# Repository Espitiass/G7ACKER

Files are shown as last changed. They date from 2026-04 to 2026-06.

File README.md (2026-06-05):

# 🤖 G7ACKER - Robot Móvil Autónomo con Visión Artificial

Sistema de robot móvil con conducción autónoma basado en visión artificial, diseñado para navegación en entornos estructurados mediante seguimiento de carril, detección de obstáculos y dirección tipo Ackermann.

---

# 📖 Descripción del Proyecto

El proyecto consiste en el desarrollo de un robot móvil autónomo que integra procesamiento visual, sensores de proximidad y control embebido distribuido para lograr un desplazamiento inteligente sin intervención humana.

El sistema está orientado a simular escenarios reales de movilidad autónoma, como vehículos terrestres a pequeña escala que operan sobre carriles definidos.

El enfoque del proyecto combina:

- Visión artificial para percepción del entorno
- Detección de estaciones mediante sensor infrarrojo
- Control distribuido (Raspberry Pi + ESP32)
- Sistema de dirección tipo Ackermann

---

# 🎥 Demo del Sistema

## Funcionamiento del robot

> *(Agregar imágenes, GIF o enlace de video del funcionamiento)*

---

# 🔄 Flujo del Sistema

```text
[Cámara IMX219]
        ↓
[Procesamiento en Raspberry Pi (OpenCV)]
        ↓
[Decisiones de navegación]
        ↓
[ESP32]
        ↓
[Driver TB6612FNG]
        ↓
[Motores JGY-370 + Servo MG90]
```

---

# 🛠️ Hardware del Sistema

## 🧠 Unidad de procesamiento

- Raspberry Pi 5
- ESP32

---

## 📡 Sensores

- Cámara IMX219 (visión artificial)
- Sensor ultrasónico HC-SR04 (detección frontal de obstáculos)
- 1 Sensor infrarrojo TCRT5000 (detección lateral de estaciones de carga y descarga)

---

## ⚙️ Actuadores

- 2 Motores DC JGY-370
- Servo motor MG90 (engranajes metálicos)

---

## 🚗 Sistema de dirección

- Configuración tipo Ackermann

---

## ⚡ Etapa de potencia

- Driver TB6612FNG Dual Motor

---

## 🔋 Alimentación

- Batería LiPo 7.4V – 5A
- Regulador XL4016 (salida a 5V, alta corriente)
- Regulador LM2596 (salida a 3.3V)

---

# 💻 Software y Tecnologías

| Tecnología | Uso |
|---|---|
| Python | Lógica principal y visión artificial |
| OpenCV | Procesamiento de imagen |
| ESP32 (C/C++) | Control embebido |
| Serial USB | Comunicación Raspberry Pi ↔ ESP32 |

---

# 📂 Estructura del Repositorio

```text
G7ACKER/
├── .vscode/                          # Configuración de Visual Studio Code
│   └── settings.json
│
├── docs/                             # Documentación del proyecto
│   ├── acta_constitucion/
│   ├── bitacoras/
│   ├── imagenes/
│   ├── matriz_control_de_documentos/
│   ├── poster/
│   ├── presentacion_final/
│   └── README.md
│
├── hardware/                         # Diseño electrónico y PCB
│   ├── esquematico/
│   ├── pcb/
│   └── README.md
│
├── mechanical/                       # Diseño mecánico y estructural
│   ├── Diseños_de_prueba/
│   ├── Diseños_finales/
│   └── README.md
│
├── src/                              # Código fuente
│   ├── Autonomía_básica/
│   ├── Control_de_motores/
│   ├── Pruebas/
│   └── README.md
│
├── .gitignore
├── LICENSE
├── README.md
├── Scriptsactivate
└── test.jpg
```

---

# 📊 Estado del Proyecto

| Módulo | Estado |
|---|---|
| Diseño electrónico | ✅ Completado |
| PCB | ✅ Fabricada y operativa |
| Sistema mecánico | ✅ Completado |
| Visión artificial | ✅ Integrada y funcional |
| Control autónomo | 🧪 Pruebas finales |

---

# 👥 Autores

| Integrante | Área |
|---|---|
| Sofía Salomé Espitia Jiménez | Área de diseño |
| Vanesa Galeano Franco | Área de programación |
| Julián Andrés García Correa | Área eléctrica y electrónica |
| Jose Lisander Hurtado Castañeda | Área mecánica |

---

# 📄 Licencia

Este proyecto se distribuye bajo la licencia MIT License.

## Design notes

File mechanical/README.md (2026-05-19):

# 🔧 Mechanical

Esta carpeta contiene todo el desarrollo mecánico del robot móvil **G7ACKER**, incluyendo diseños CAD, prototipos, soportes estructurales y versiones finales utilizadas durante la construcción del sistema robótico.

El objetivo principal de este módulo es diseñar y fabricar la estructura física del robot, garantizando:

- Resistencia mecánica
- Estabilidad estructural
- Integración electrónica
- Soporte de sensores
- Sistema de dirección
- Sistema de tracción
- Modularidad del diseño

Todos los componentes fueron desarrollados considerando la integración entre:

- Raspberry Pi 5
- ESP32
- Sensores
- Sistema de locomoción
- Cámaras
- Actuadores

---

# 📂 Estructura de la carpeta

La carpeta se encuentra dividida en dos grandes secciones:

| Carpeta | Descripción |
|---|---|
| `Diseños_de_prueba` | Modelos preliminares y prototipos utilizados durante el desarrollo |
| `Diseños_finales` | Versiones finales implementadas en el robot |

---

# 🧪 Diseños_de_prueba

Esta sección contiene las primeras iteraciones y prototipos mecánicos desarrollados durante la etapa de diseño del robot.

Aquí se realizaron pruebas relacionadas con:

- Dimensiones del chasis
- Sistemas de dirección
- Ubicación de sensores
- Integración de cámara
- Soportes estructurales
- Distribución de componentes

Los modelos incluidos permitieron validar conceptos antes de fabricar las versiones finales.

## 📁 Contenido

### `bases`
Diseños iniciales del chasis y estructura principal del robot.

### `Camara`
Primeros soportes y adaptaciones para el montaje de la cámara del sistema de visión.

### `direccion_v1`
Primera versión del sistema de dirección mecánica.

### `direccion_v2`
Segunda iteración del mecanismo de dirección con mejoras estructurales y de movilidad.

### `traccion_v1`
Primer prototipo del sistema de tracción y montaje de motores.

---

# ✅ Diseños_finales

Esta sección contiene las piezas y modelos mecánicos definitivos utilizados en la construcción final del robot G7ACKER.

Los diseños finales fueron optimizados para:

- Mejor estabilidad
- Integración electrónica
- Facilidad de ensamblaje
- Reducción de vibraciones
- Organización del cableado
- Soporte robusto de sensores

## 📁 Contenido

### `Bases`
Estructura principal final del robot, utilizada para soportar todos los módulos mecánicos y electrónicos.

### `direccion_v3`
Versión final del sistema de dirección implementado en el robot.

Incluye mejoras en:

- Precisión de giro
- Resistencia mecánica
- Integración con servomotor
- Estabilidad de movimiento

### `Soporte_camara`
Soporte definitivo para la cámara principal utilizada por el sistema de visión artificial.

### `soporte_infrarrojo`
Estructura diseñada para fijar y posicionar el sensor infrarrojo del robot.

### `soporte_lipo_v1`
Soporte mecánico para la batería LiPo utilizada como fuente de alimentación del sistema.

### `soporte_ultrasonico`
Montaje diseñado para el sensor ultrasónico encargado de la detección de obstáculos.

### `Tracción`
Sistema final de montaje de motores, ruedas y transmisión del robot móvil.

---

# ⚙️ Diseño mecánico del robot

El diseño mecánico del robot fue desarrollado utilizando herramientas CAD y técnicas de fabricación digital.

El sistema fue diseñado considerando:

- Distribución de peso
- Centro de gravedad
- Espacio para electrónica
- Accesibilidad de mantenimiento
- Modularidad
- Expansión futura

La estructura permite integrar de manera eficiente todos los módulos electrónicos y sensores del sistema autónomo.

---

# 🛠️ Fabricación

Las piezas fueron diseñadas principalmente para fabricación mediante impresión 3D, utilizando materiales termoplásticos compatibles con tecnologías FDM.

Esto permitió:

- Fabricación rápida de prototipos
- Iteración constante de diseños
- Reducción de costos
- Personalización de componentes

---

# 🚗 Función dentro del proyecto

El módulo mecánico constituye la base física del robot móvil G7ACKER.

Su función principal es proporcionar:

- Soporte estructural
- Integración de sensores
- Sistema de locomoción
- Protección de componentes electrónicos
- Plataforma de navegación autónoma

La integración entre diseño mecánico, electrónica y software permitió construir un sistema robótico funcional, modular y escalable.

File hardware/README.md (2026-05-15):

# Diseño Electrónico

Esta carpeta contiene el desarrollo del sistema electrónico del robot G7ACKER, incluyendo el diseño del esquemático y la PCB utilizada para la integración del sistema.

---

## Estructura

```text
hardware/
│── esquematico/
│── pcb/
```

---

## Contenido

### Esquemático

Incluye la representación del sistema electrónico antes de su implementación física:

* Imagen del esquemático por medio de ilustración en el sofware DRAW.IO (formato PNG) para visualización rápida
* Archivo original del esquemático (formato `.sch`) con todas las conexiones y componentes definidos
* Imagen del esquematico original en FUSION

Este diseño permite validar la correcta interconexión de los módulos antes de avanzar al diseño de la PCB.

---

### PCB

Contiene el diseño final de la placa electrónica:

* Archivo de la PCB con ruteo completo (formato `.f3z`, Fusion 360)
* Modelo 3D de la PCB (formato `.brd`)
* Imagen del ruto de la pcb en FUSION

Este diseño corresponde a la versión enviada a fabricación, incluyendo:

* Rutas eléctricas
* Distribución de componentes
* Integración del sistema completo

---

## Propósito

* Documentar el diseño electrónico del sistema
* Facilitar la fabricación de la PCB
* Permitir la revisión y modificación del circuito
* Servir como base para futuras iteraciones

---

## Notas

* Mantener consistencia entre esquemático y PCB
* Verificar nombres de componentes y conexiones
* Evitar modificaciones directas sobre versiones finales sin control

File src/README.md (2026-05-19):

# 📁 Carpeta de Código Fuente 

En esta carpeta se encuentra el **código fuente del robot móvil autónomo G7ACKER**, desarrollado para implementar las funcionalidades principales de **control, percepción, comunicación y pruebas del sistema**.

Aquí se almacenan los diferentes scripts utilizados durante el desarrollo del proyecto, incluyendo módulos de control de hardware, visión artificial, comunicación serial y pruebas individuales de componentes.

El objetivo de esta carpeta es **centralizar todo el software del sistema**, permitiendo organizar, modificar y escalar el desarrollo del robot de manera estructurada.

---

# 🧩 Estructura del proyecto

La organización del código se divide en diferentes módulos según la funcionalidad desarrollada dentro del robot.

---

## 🤖 Autonomía_básica/

Esta carpeta contiene los algoritmos relacionados con la **navegación autónoma básica del robot**, incluyendo seguimiento de carriles, detección de obstáculos y toma de decisiones sobre la pista.

La carpeta se divide en dos versiones principales:

### 📂 V1/

Contiene la primera versión funcional del sistema de autonomía básica del robot.

En esta etapa se desarrollaron e integraron:

- Seguimiento de líneas o carriles.
- Detección de obstáculos mediante sensor ultrasónico.
- Control básico de desplazamiento autónomo.

Esta versión representa la primera implementación estable de navegación autónoma sobre pista.

---

### 📂 V2/

Corresponde a la versión más reciente y estructurada del sistema de autonomía básica.

Esta versión divide las funciones principales del robot en diferentes módulos:

- `main.py`  
  Archivo principal encargado de iniciar y coordinar la ejecución del sistema.

- `motor_control.py`  
  Gestiona el control de movimiento del robot, la activación de motores y la comunicación con la ESP32.

- `qr_logic.py`  
  Procesa la información obtenida mediante lectura de códigos QR y toma decisiones de navegación dentro de la pista.

Esta estructura modular permite separar la lógica de navegación, percepción y control, facilitando la organización y escalabilidad del proyecto.

---

## ⚙️ Control_de_motores/

Esta carpeta contiene el código desarrollado para el control de los motores y actuadores del robot desde la ESP32.

Aquí se encuentra la versión final del sistema de control:

- `control_1.2.cpp`

Este código es el encargado de:

- Recibir las instrucciones enviadas desde la Raspberry Pi 5.
- Interpretar los comandos de movimiento.
- Controlar los motores mediante señales enviadas al driver.
- Ejecutar acciones como avance, retroceso, giros y detención del robot.

Además, dentro de esta carpeta se encuentran versiones previas y pruebas realizadas durante el desarrollo del sistema de control.

---

## 🧪 Pruebas/

Esta carpeta contiene todas las pruebas realizadas de manera independiente sobre sensores, actuadores y sistemas de comunicación del robot.

El objetivo de estas pruebas es:

- Validar el funcionamiento individual de cada componente.
- Detectar errores antes de integrar los módulos al sistema principal.
- Facilitar la depuración del hardware y software.
- Comprobar estabilidad y comunicación entre dispositivos.

Dentro de esta carpeta se incluyen pruebas relacionadas con:

### 📷 Cámara
Pruebas de captura de imagen, procesamiento y funcionamiento de la cámara.

### 🔌 Comunicación serial
Pruebas de comunicación entre Raspberry Pi y ESP32.

### 📡 Sensores
Pruebas individuales de sensores ultrasónicos, sensores IR y finales de carrera.

### ⚙️ Motores
Pruebas de velocidad, RPM, encoders y control de motores.

### 🔄 Servo motores
Pruebas de funcionamiento y posicionamiento del servomotor.

### 🏁 Integración final
Pruebas completas del comportamiento del robot sobre la pista.

---

# ⚙️ Organización del código

El proyecto sigue un enfoque de desarrollo **modular**, donde cada archivo cumple una función específica dentro del sistema general del robot.

Esta metodología permite:

- Facilitar la comprensión del sistema.
- Mejorar la depuración del código.
- Integrar nuevas funcionalidades sin afectar otros módulos.
- Mantener un desarrollo organizado y escalable.
- Favorecer el trabajo colaborativo dentro del equipo.

Además, se manejan múltiples versiones y pruebas progresivas para validar el funcionamiento del robot antes de integrar cada componente al sistema principal.

---

# 🚀 Desarrollo continuo

El proyecto se encuentra en constante evolución, por lo que esta carpeta seguirá creciendo con nuevos módulos y mejoras relacionadas con:

- Navegación autónoma
- Visión artificial
- Integración de sensores
- Comunicación entre sistemas
- Optimización de control
- Automatización de decisiones
- Mejora del rendimiento general del robot

Por esta razón, el contenido de esta carpeta puede actualizarse continuamente a medida que avance el desarrollo del robot móvil autónomo G7ACKER.

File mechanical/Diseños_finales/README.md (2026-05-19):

# 📁 Diseños_finales

La carpeta `Diseños_finales` contiene las versiones finales y optimizadas de los componentes mecánicos utilizados en el robot móvil **G7ACKER**.

Estos diseños corresponden a las iteraciones definitivas desarrolladas después de las etapas de prueba y validación mecánica realizadas durante el prototipado inicial del robot.

En esta sección se consolidan los modelos utilizados para:

- Chasis estructural
- Sistema de dirección Ackerman
- Sistema de tracción
- Soportes electrónicos
- Integración de sensores
- Sistema de cámara
- Distribución mecánica final

Todos los modelos fueron desarrollados para fabricación mediante impresión 3D y ensamblaje modular.

---

# 📂 Estructura de archivos

Dentro de cada subcarpeta se incluyen principalmente los siguientes tipos de archivos:

| Extensión | Descripción |
|---|---|
| `.f3d` | Archivo editable de Autodesk Fusion 360 |
| `.stl` | Modelo 3D listo para impresión |
| `.pdf` | Documento técnico o plano de referencia |

Los archivos `.f3d` permiten modificar los diseños mecánicos, mientras que los `.stl` corresponden a versiones preparadas para fabricación mediante impresión 3D.

---

# 📁 Bases

La carpeta `Bases` contiene los diseños estructurales finales del chasis principal del robot.

Estos modelos fueron desarrollados para proporcionar:

- Rigidez estructural
- Distribución de carga
- Espacio para electrónica
- Integración de sensores
- Soporte para sistemas mecánicos

## 📄 Componentes principales

| Archivo | Descripción |
|---|---|
| `Base piso de carga 3 carga.f3d` | Diseño estructural principal del piso de carga |
| `Base piso de carga 3 carga.stl` | Modelo STL del piso de carga |
| `Base Piso_1 mot_ack.f3d` | Base estructural para integración del sistema Ackerman |
| `Base Piso_2 electronica.f3d` | Base destinada al montaje electrónico |
| `base_piso_1_mat_ack.f3d` | Variante estructural del sistema Ackerman |
| `Base_Piso_2_electronica.pdf` | Plano técnico de integración electrónica |

---

# 📁 direccion_v3

La carpeta `direccion_v3` contiene la tercera versión del sistema de dirección mecánica del robot.

Esta versión incorpora mejoras estructurales y funcionales orientadas a:

- Mayor precisión de giro
- Mejor estabilidad mecánica
- Reducción de holguras
- Integración optimizada del servomotor
- Mayor resistencia estructural

El diseño continúa basado en un sistema tipo Ackerman para mejorar el control de trayectoria del robot.

## 📄 Componentes principales

| Componente | Función |
|---|---|
| `Acople rueda delantera.pdf` | Plano técnico del acople de rueda delantera |
| `Barra direccion version 3.pdf` | Documento técnico de la barra de dirección |
| `barra_direccion_v3.f3d` | Diseño editable de la barra de dirección |
| `barra_direccion_v3.stl` | Modelo imprimible de la barra de dirección |
| `barra_soportes_giratorios_v3.f3d` | Soporte estructural giratorio |
| `barra_soportes_giratorios_v3.stl` | Modelo STL del soporte giratorio |
| `base_brazo_servo.f3d` | Base de integración del brazo del servomotor |
| `base_brazo_servo.stl` | Modelo STL del brazo del servo |
| `bujes_rigidez.f3d` | Elementos de refuerzo estructural |
| `bujes_rigidez.stl` | Modelo imprimible de los bujes |
| `Soporte giratorio ackerman.pdf` | Plano del soporte Ackerman |
| `Soporte servo RH.pdf` | Plano técnico del soporte derecho del servo |
| `soporte_giratorio_ackerman.f3d` | Diseño del soporte Ackerman |
| `soporte_giratorio_ackerman.stl` | Modelo STL del soporte Ackerman |
| `soporte_servo_der.f3d` | Soporte derecho del servomotor |
| `soporte_servo_der.stl` | Modelo imprimible del soporte derecho |
| `soporte_servo_izq.f3d` | Soporte izquierdo del servomotor |
| `soporte_servo_izq.stl` | Modelo imprimible del soporte izquierdo |

Todos los componentes se encuentran disponibles en formatos editables y preparados para impresión 3D.

---

# 📁 Soporte camara

La carpeta `Soporte camara` contiene los diseños finales del sistema de soporte de cámara del robot.

Estos modelos fueron desarrollados para garantizar:

- Estabilidad mecánica
- Correcto ángulo de visión
- Integración con Raspberry Pi
- Protección estructural de la cámara
- Modularidad de ensamblaje

## 📄 Componentes principales

| Componente | Función |
|---|---|
| `base camara.f3d` | Base principal del sistema de cámara |
| `base camara.stl` | Modelo STL de la base |
| `Ensamble camara 2.f3d` | Ensamble mecánico del sistema de cámara |
| `Ensamble camara 2.stl` | Modelo STL del ensamble |
| `Pilar camara V3.f3d` | Pilar estructural de soporte |
| `Pilar camara V3.stl` | Modelo imprimible del pilar |
| `Soporte superior camara.f3d` | Soporte superior del sistema |
| `Soporte superior camara.stl` | Modelo STL del soporte superior |

---

# 📁 soporte_infrarrojo

La carpeta `soporte_infrarrojo` contiene el soporte mecánico diseñado para la integración de sensores infrarrojos.

Estos diseños permiten:

- Montaje seguro del sensor
- Correcta orientación de lectura
- Protección mecánica
- Integración con el chasis

## 📄 Archivos principales

| Archivo | Descripción |
|---|---|
| `soporte_infrarrojo.f3d` | Diseño editable del soporte infrarrojo |
| `soporte_infrarrojo.stl` | Modelo STL listo para impresión |

---

# 📁 soporte_lipo_v1

La carpeta `soporte_lipo_v1` contiene el sistema de soporte diseñado para la batería LiPo utilizada en el robot.

Este soporte fue desarrollado para:

- Fijación segura de batería
- Distribución de peso
- Protección mecánica
- Fácil mantenimiento

## 📄 Archivos principales

| Archivo | Descripción |
|---|---|
| `soporte_bateria_v1.f3d` | Diseño editable del soporte de batería |
| `soporte_bateria_v1.stl` | Modelo STL para impresión 3D |

---

# 📁 soporte_ultrasonico

La carpeta `soporte_ultrasonico` contiene los soportes mecánicos destinados a sensores ultrasónicos del robot.

Estos componentes permiten:

- Integración estructural del sensor
- Correcta orientación de medición
- Protección física
- Fácil montaje sobre el chasis

## 📄 Archivos principales

| Archivo | Descripción |
|---|---|
| `soporte_ultrasonico.f3d` | Diseño editable del soporte ultrasónico |
| `soporte_ultrasonico.stl` | Modelo imprimible del soporte |

---

# 📁 Tracción

La carpeta `Tracción` contiene los diseños finales del sistema de transmisión y montaje de motores del robot.

Estos modelos fueron desarrollados para optimizar:

- Integración de motores
- Acople de ruedas
- Distribución de fuerza
- Estabilidad mecánica
- Soporte estructural del sistema de tracción

## 📄 Componentes principales

| Componente | Función |
|---|---|
| `Acople de la llanta al GearBox.pdf` | Plano técnico del sistema de acople |
| `acople_llanta_motor.f3d` | Diseño editable del acople rueda-motor |
| `acople_llanta_motor.stl` | Modelo STL del acople |
| `Soporte de motor derecho.pdf` | Plano técnico del soporte derecho |
| `Soporte de motor izquierdo.pdf` | Plano técnico del soporte izquierdo |
| `soporte_motor_derecho.f3d` | Soporte estructural derecho |
| `soporte_motor_derecho.stl` | Modelo imprimible del soporte derecho |
| `soporte_motor_izquierdo.f3d` | Soporte estructural izquierdo |
| `soporte_motor_izquierdo.stl` | Modelo imprimible del soporte izquierdo |

---

# 🛠️ Fabricación de componentes

Todos los modelos STL incluidos en esta carpeta fueron diseñados para fabricación mediante impresión 3D utilizando tecnología FDM.

Esto permitió:

- Fabricación rápida de componentes
- Ajustes iterativos
- Validación física de piezas
- Reducción de costos
- Desarrollo modular del robot

---

# ⚙️ Flujo de desarrollo mecánico

El proceso de diseño utilizado para el desarrollo de los componentes finales siguió una metodología iterativa basada en:

1. Diseño CAD en Fusion 360.
2. Simulación y validación estructural.
3. Exportación de archivos STL.
4. Impresión 3D de prototipos.
5. Ensamble mecánico.
6. Integración electrónica.
7. Pruebas funcionales.
8. Optimización final.

---

# 🚀 Importancia dentro del proyecto

Los diseños finales representan la consolidación del sistema mecánico desarrollado para el robot móvil autónomo G7ACKER.

Gracias a esta etapa fue posible:

- Obtener un sistema mecánico estable
- Mejorar la precisión de dirección
- Optimizar la integración electrónica
- Reducir vibraciones estructurales
- Mejorar la distribución de peso
- Facilitar el ensamblaje modular
- Garantizar compatibilidad con sensores y actuadores

Esta carpeta contiene los modelos definitivos utilizados en la construcción física del robot.

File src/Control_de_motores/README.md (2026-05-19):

# ⚙️ Control de Motores

Esta carpeta contiene el desarrollo del sistema de **control de movimiento del robot móvil G7ACKER**, implementado sobre un microcontrolador ESP32.

El objetivo principal de este módulo es recibir las instrucciones enviadas desde la Raspberry Pi y convertirlas en acciones físicas sobre el robot, controlando:

- Motores de tracción
- Dirección del sistema
- Velocidad de desplazamiento
- Lectura de encoders
- Control PWM
- Servomotor de dirección

Este sistema constituye la capa de ejecución del robot, encargada de transformar las decisiones del sistema autónomo en movimiento real.

---

# 📂 Contenido de la carpeta

Dentro de esta carpeta se encuentran distintas versiones y pruebas relacionadas con el control de motores del robot.

La versión principal y final utilizada en el proyecto corresponde a:

- `control_1.2.cpp`

Además, se incluyen archivos de prueba y calibración utilizados durante el desarrollo.

---

# 📄 control_1.2.cpp

El archivo `control_1.2.cpp` corresponde a la versión final del sistema de control implementado en el ESP32.

Este código se encarga de:

- Recibir comandos desde la Raspberry Pi mediante comunicación serial.
- Controlar los motores DC del robot.
- Gestionar el movimiento diferencial.
- Accionar el servomotor de dirección.
- Leer encoders para medición de velocidad.
- Ejecutar el control de tracción del robot.

---

# 🔌 Comunicación con Raspberry Pi

El ESP32 recibe comandos enviados desde la Raspberry Pi mediante comunicación serial USB.

Los comandos implementados son:

| Comando | Acción |
|---|---|
| `a` | Avanzar |
| `i` | Girar izquierda |
| `d` | Girar derecha |
| `x` | Detener |

Cada instrucción es interpretada por el ESP32 para ejecutar el movimiento correspondiente sobre el sistema de tracción.

Esta arquitectura permite separar:

- Raspberry Pi → procesamiento y toma de decisiones.
- ESP32 → control físico de actuadores.

---

# 🚗 Sistema de movimiento

El robot utiliza un sistema de tracción diferencial compuesto por:

- Dos motores DC con caja reductora.
- Driver de potencia.
- Control PWM independiente para cada motor.

El código controla de manera individual ambos motores para generar:

- Movimiento frontal
- Correcciones de trayectoria
- Giros
- Frenado

---

# ⚡ Control PWM

La velocidad de los motores se regula mediante señales PWM generadas por el ESP32.

El sistema utiliza:

- Canal PWM independiente para cada motor.
- Frecuencia configurada a 5 kHz.
- Resolución de 8 bits.

Esto permite controlar la velocidad del robot de manera eficiente y suave.

---

# 📏 Calibración de motores

Debido a diferencias mecánicas entre motores, se implementaron ecuaciones de calibración independientes para cada lado del sistema de tracción.

Estas ecuaciones permiten compensar diferencias de velocidad y mantener un desplazamiento más estable y recto.

El sistema utiliza constantes de ajuste para:

- Motor izquierdo
- Motor derecho

De esta manera se mejora la precisión del movimiento autónomo del robot.

---

# 🔄 Control diferencial

El movimiento del robot se implementa mediante lógica diferencial.

Dependiendo del comando recibido:

- Ambos motores avanzan.
- Un motor se detiene.
- Se generan correcciones de dirección.

Esto permite realizar giros y ajustes de trayectoria sin necesidad de mecanismos complejos de dirección.

---

# 🎯 Control del servomotor

El sistema incorpora un servomotor encargado de modificar la dirección mecánica del robot.

El servo se posiciona según el movimiento solicitado:

| Dirección | Ángulo aproximado |
|---|---|
| Centro | 90° |
| Derecha | 150° |
| Izquierda | 30° |

El código evita movimientos innecesarios del servo utilizando una variable de control que detecta cambios de dirección.

Esto reduce vibraciones y mejora la estabilidad mecánica.

---

# 📡 Lectura de encoders

El sistema utiliza encoders para medir la velocidad de rotación de los motores.

Las señales de encoder son capturadas mediante interrupciones del ESP32 para obtener:

- Pulsos por revolución (PPR)
- RPM
- Velocidad lineal aproximada

Esto permite monitorear el comportamiento real de los motores durante el desplazamiento.

---

# ⚙️ Arquitectura del sistema

El código fue desarrollado utilizando una estructura modular basada en funciones independientes para:

- Movimiento de motores
- Frenado
- Control PWM
- Lectura de encoders
- Movimiento del servo
- Aplicación de trayectorias

Esta organización facilita:

- Mantenimiento del código
- Escalabilidad
- Pruebas individuales
- Depuración del sistema

---

# 🧪 Desarrollo y pruebas

Durante el desarrollo se realizaron múltiples pruebas relacionadas con:

- Control de velocidad
- Estabilidad del movimiento
- Respuesta del servo
- Comunicación serial
- Medición de RPM
- Ajuste de PWM
- Corrección de trayectoria

Las distintas versiones del código reflejan el proceso iterativo de mejora del sistema de locomoción.

---

# 🚀 Función dentro del robot

Este módulo representa la capa de ejecución física del robot móvil G7ACKER.

Mientras la Raspberry Pi procesa información del entorno y toma decisiones autónomas, el ESP32 ejecuta dichas acciones controlando directamente los actuadores del sistema.

La integración entre ambos dispositivos permite implementar un sistema robótico distribuido, modular y escalable.

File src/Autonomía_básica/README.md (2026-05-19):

# 🤖 Autonomía Básica

Esta carpeta contiene el desarrollo del sistema de **autonomía básica del robot móvil G7ACKER**, encargado del seguimiento de líneas, detección de obstáculos, lectura de códigos QR/AprilTags y toma de decisiones dentro de la pista.

Aquí se encuentran las diferentes versiones del sistema autónomo implementadas durante el desarrollo del proyecto, permitiendo observar la evolución desde las primeras pruebas funcionales hasta la arquitectura final de navegación.

El objetivo principal de esta sección es integrar los módulos de:

- Visión artificial
- Seguimiento de carriles
- Detección de obstáculos
- Comunicación con el ESP32
- Navegación autónoma
- Toma de decisiones basada en señales visuales

---

# 📂 Estructura de la carpeta

La carpeta se divide en dos versiones principales del sistema:

- `V1/` → Primera versión funcional del sistema autónomo.
- `V2/` → Versión final e integrada de autonomía básica.

---

# 🔹 V1 — Primera versión funcional

La carpeta `V1` contiene la primera implementación estable del sistema de autonomía básica del robot.

Esta versión se enfocó principalmente en:

- Seguimiento de líneas mediante visión artificial.
- Detección de obstáculos usando sensor ultrasónico.
- Comunicación serial con el ESP32.
- Visualización del procesamiento en tiempo real mediante Flask.

---

## ⚙️ Funcionalidades implementadas en V1

### 👁️ Detección de carriles

El sistema utiliza una cámara conectada a la Raspberry Pi para capturar imágenes en tiempo real y detectar las líneas de navegación presentes en la pista.

Para ello se implementaron técnicas de procesamiento de imagen utilizando OpenCV:

- Conversión a espacio de color HSV.
- Aplicación de máscaras por color.
- Filtrado morfológico.
- Detección de contornos.
- Cálculo dinámico del centro del carril.

El algoritmo identifica las líneas izquierda y derecha de la pista y calcula el error respecto al centro de la imagen para corregir la trayectoria del robot.

---

### 📡 Detección de obstáculos

Se integró un sensor ultrasónico conectado a la Raspberry Pi mediante GPIO para detectar obstáculos frente al robot.

El sistema realiza múltiples lecturas consecutivas para reducir ruido y falsas detecciones.

Cuando un objeto es detectado a una distancia menor al umbral establecido:

- El robot detiene inmediatamente su movimiento.
- Se bloquea el envío de comandos de avance.
- Se muestra el estado del sensor en el stream de video.

---

### 🔌 Comunicación serial con ESP32

La Raspberry Pi envía comandos de movimiento al ESP32 mediante comunicación serial USB.

Los comandos implementados permiten:

- Avanzar
- Girar a la izquierda
- Girar a la derecha
- Detener el robot

Esta arquitectura divide el sistema en:

- Raspberry Pi → procesamiento y toma de decisiones.
- ESP32 → ejecución de movimiento y control de motores.

---

### 📺 Streaming en tiempo real

La versión V1 implementa un servidor Flask para visualizar el procesamiento de imagen en tiempo real desde cualquier navegador conectado a la red local.

El stream incluye:

- Detección de líneas
- Contornos encontrados
- Centro del carril
- Estado del ultrasonido
- Dirección actual
- Comando enviado

Esto permitió facilitar el proceso de depuración y ajuste del sistema autónomo.

---

# 🔹 V2 — Versión final de autonomía básica

La carpeta `V2` contiene la arquitectura final del sistema autónomo del robot.

Esta versión integra:

- Seguimiento de líneas
- Detección de obstáculos
- Lectura de QR / AprilTags
- Máquina de estados
- Navegación por estaciones
- Comunicación entre procesos
- Control inteligente de recorrido

La arquitectura fue separada en múltiples módulos para mejorar:

- Organización del código
- Escalabilidad
- Mantenimiento
- Depuración

---

# 📄 main.py

El archivo `main.py` actúa como el núcleo principal del sistema autónomo.

Su función es:

- Inicializar el sistema.
- Crear procesos independientes.
- Gestionar la comunicación entre módulos.
- Ejecutar el sistema de navegación.

Para ello se implementa `multiprocessing`, permitiendo ejecutar distintos procesos simultáneamente sin bloquear el procesamiento de cámara.

---

## 🔄 Comunicación entre procesos

El sistema utiliza colas (`Queue`) para compartir información entre módulos:

- `qr_queue` → IDs detectados.
- `action_queue` → acciones de movimiento.
- `line_status_queue` → estado de detección de líneas.
- `status_queue` → información general del robot.

Esta arquitectura modular facilita el intercambio de información entre los distintos componentes del sistema autónomo.

---

# 📄 motor_control.py

El archivo `motor_control.py` es el encargado del procesamiento principal relacionado con:

- Visión artificial
- Seguimiento de línea
- Lectura de QR
- Detección de obstáculos
- Comunicación serial
- Streaming del sistema

Este módulo constituye el núcleo de percepción del robot.

---

## 👁️ Seguimiento de línea

El sistema detecta líneas de color mediante OpenCV utilizando máscaras HSV y análisis de contornos.

A partir de la posición del carril detectado se calcula el error respecto al centro de la imagen para decidir:

- Avanzar
- Girar a la izquierda
- Girar a la derecha
- Detenerse

---

## 📷 Lectura de QR y AprilTags

La versión V2 incorpora un sistema de lectura de QR/AprilTags utilizado para identificar estaciones y tomar decisiones dentro de la pista.

El sistema:

- Detecta marcos visuales.
- Se aproxima automáticamente.
- Captura la región de interés.
- Decodifica el identificador.
- Envía la información al módulo lógico.

Esto permite que el robot navegue de forma autónoma según el recorrido establecido.

---

## 📡 Sensor ultrasónico

El módulo también integra el sensor ultrasónico para detener el robot ante obstáculos cercanos.

La prioridad del sensor es superior al seguimiento de línea, por lo que cualquier detección bloquea inmediatamente el movimiento del robot.

---

## 📺 Visualización y depuración

El sistema genera un stream de video en tiempo real mostrando:

- Estado actual
- Carriles detectados
- Detección de QR
- Comandos enviados
- Distancia detectada
- Variables internas del sistema

Esto facilita el monitoreo del comportamiento autónomo durante las pruebas.

---

# 📄 qr_logic.py

El archivo `qr_logic.py` contiene la lógica de navegación y toma de decisiones del robot.

Este módulo implementa una máquina de estados encargada de interpretar los IDs detectados y decidir el comportamiento del robot dentro de la pista.

---

# 🧠 Máquina de estados

La lógica del sistema se organiza mediante estados secuenciales que representan cada etapa del recorrido.

Algunos estados implementados son:

- Espera de carga
- Espera de objetivo
- Espera de giro
- Espera de descarga
- Fin de recorrido

Cada transición depende de:

- IDs detectados
- Sensores
- Estado del robot
- Posición dentro de la pista

---

# 🗺️ Mapa de tags

El sistema utiliza un diccionario (`MAPA_TAGS`) donde cada ID representa una acción o estación específica.

Por ejemplo:

- Estaciones de carga
- Estaciones de descarga
- Intersecciones
- Direcciones de giro
- Finales de recorrido

Esto permite modificar el comportamiento del robot simplemente cambiando la configuración lógica de los tags.

---

# 📡 Integración de sensores

Además de la visión artificial, este módulo integra:

- Sensor infrarrojo
- Final de carrera
- Estado de líneas detectadas

La combinación de sensores permite aumentar la confiabilidad del sistema de navegación autónoma.

---

# ⚙️ Arquitectura modular

La versión V2 fue desarrollada siguiendo una arquitectura modular distribuida, donde cada archivo cumple una función específica dentro del sistema.

Esto permite:

- Escalar funcionalidades.
- Modificar módulos sin afectar el resto del sistema.
- Facilitar pruebas individuales.
- Mejorar la mantenibilidad del proyecto.

---

# 🚀 Evolución del sistema

La transición de V1 a V2 representa la evolución del robot desde un sistema básico de seguimiento de líneas hasta una plataforma de navegación autónoma capaz de:

- Interpretar señales visuales.
- Tomar decisiones.
- Navegar entre estaciones.
- Gestionar recorridos.
- Integrar múltiples sensores.
- Coordinar distintos procesos simultáneamente.

Esta arquitectura constituye la base del sistema autónomo implementado en el robot móvil G7ACKER.

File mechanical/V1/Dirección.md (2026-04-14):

# Dirección

El sistema de **dirección del robot** fue diseñado utilizando **Autodesk Fusion 360**, con el objetivo de implementar un mecanismo de giro preciso que permita orientar las ruedas delanteras del robot durante su desplazamiento.

Para este proyecto se estableció un sistema de **dirección tipo Ackermann**, ampliamente utilizado en vehículos terrestres debido a su capacidad de reducir el deslizamiento lateral de las ruedas durante los giros. Este tipo de mecanismo permite que cada rueda del eje delantero describa un radio de giro diferente, mejorando la eficiencia del movimiento y la estabilidad del robot.

El sistema de dirección es accionado mediante un **servo motor SG90**, el cual transmite el movimiento a través de un sistema de **piñón y engranaje**, permitiendo transformar el movimiento angular del servo en el desplazamiento del mecanismo de dirección.

Durante el proceso de diseño se modelaron todas las piezas del sistema dentro de **Fusion 360**, con el objetivo de verificar:

- Correcta integración entre componentes.
- Espacio suficiente para el movimiento de las piezas.
- Posibles interferencias mecánicas.
- Alineación adecuada del sistema de dirección.

Posteriormente, los componentes fueron **fabricados mediante impresión 3D**, lo cual permite obtener geometrías personalizadas y facilita la iteración rápida durante el proceso de desarrollo.

---

# SG90 Servo Motor

[Link al diseño en Fusion 360](https://a360.co/3P9kEA0)
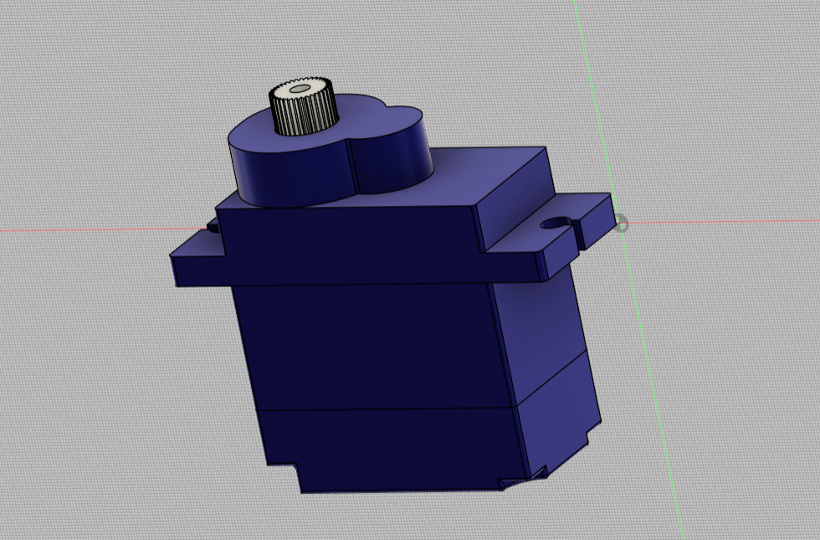
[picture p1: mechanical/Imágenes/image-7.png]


El **servo motor SG90** es el actuador encargado de generar el movimiento del sistema de dirección.

Este tipo de servo es utilizado en este proyecto de robot de conducción autónoma debido a su:

- Bajo peso.
- Tamaño compacto.
- Facilidad de control mediante señales PWM.
- Buena relación entre torque y consumo energético.

Dentro del sistema de dirección, el servo transmite su movimiento rotacional a un **piñón**, el cual engrana con una rueda dentada de mayor diámetro. Este mecanismo permite **aumentar la precisión del movimiento y mejorar el control del ángulo de giro**.

El modelo del servo fue incluido dentro del entorno CAD con el propósito de **verificar su correcta integración mecánica con el resto del sistema**.

---

# Piñón Servo

[Link al diseño en Fusion 360](https://a360.co/4cQ5PMJ)
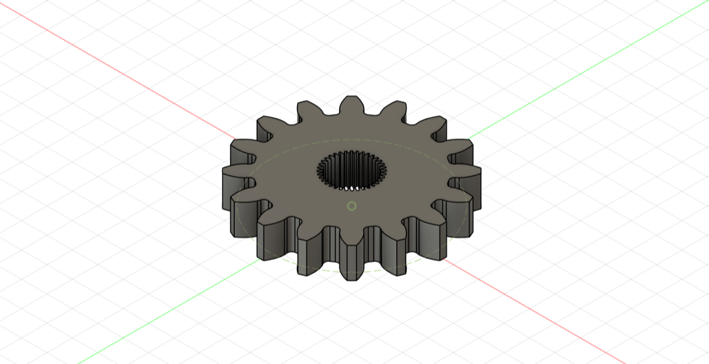
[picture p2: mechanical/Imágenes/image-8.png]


El **piñón del servo** es la pieza encargada de transmitir el movimiento rotacional del servo hacia el engranaje principal del sistema de dirección.

Este componente se fija directamente al eje del servo motor y engrana con la pieza llamada **Engranaje de brazo**, permitiendo transferir el movimiento de forma eficiente.

El diseño del piñón fue realizado considerando:

- El diámetro del eje del servo.
- El módulo del engranaje.
- La correcta alineación con el engranaje principal.

Esta pieza fue **fabricada mediante impresión en resina**, lo que permite ajustar con precisión las dimensiones necesarias para su correcta integración con el servo.

---

# Engranaje Brazo

[Link al diseño en Fusion 360](https://a360.co/4ux1Vie)
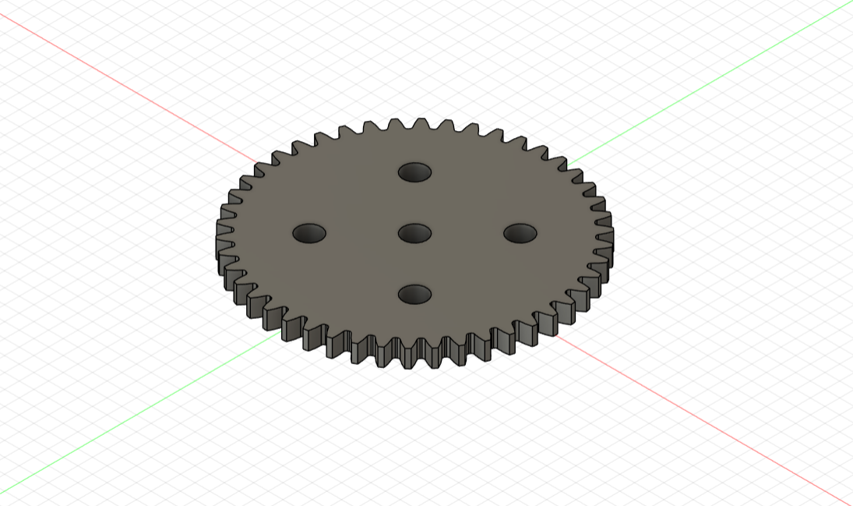
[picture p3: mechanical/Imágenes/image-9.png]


El **engranaje del brazo de dirección** es la pieza encargada de recibir el movimiento del piñón del servo y transmitirlo hacia el mecanismo de dirección.

Gracias a su mayor diámetro en comparación con el piñón, este engranaje permite:

- Aumentar la precisión del movimiento.
- Reducir la velocidad angular.
- Mejorar el control del sistema de dirección.

Este componente se encuentra conectado al **brazo de dirección**, el cual convierte el movimiento rotacional en desplazamiento lateral del sistema Ackermann. Esta pieza también fue **fabricada mediante impresión en resina.**

---

# Brazo Direccion

[Link al diseño en Fusion 360](https://a360.co/4ltEYrR)
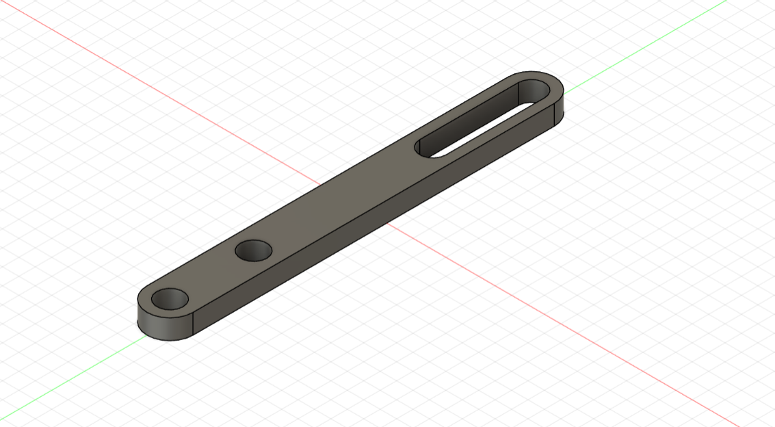
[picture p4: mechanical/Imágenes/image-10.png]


El **brazo de dirección** es el elemento encargado de transmitir el movimiento proveniente del engranaje hacia las barras que controlan la orientación de las ruedas.

Su función principal es **transformar el movimiento rotacional del sistema de engranajes**, necesario para accionar el mecanismo Ackermann.

El diseño de esta pieza busca garantizar:

- Rigidez estructural.
- Correcta transmisión del movimiento.
- Compatibilidad con las barras de dirección.

---

# Barra Direccion

[Link al diseño en Fusion 360](https://a360.co/4lwSNpI)
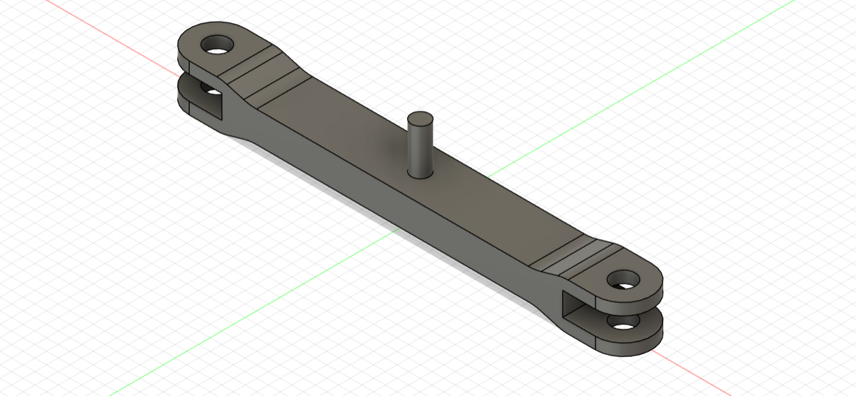
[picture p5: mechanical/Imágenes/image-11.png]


La **barra de dirección** conecta ambos lados del sistema Ackermann, permitiendo que el movimiento generado por el brazo de dirección se transmita a las ruedas delanteras.

Esta barra es responsable de:

- Sincronizar el movimiento de las ruedas.
- Mantener la geometría correcta del sistema de dirección.
- Permitir que cada rueda gire en un ángulo diferente durante las curvas.

Este comportamiento es fundamental para el funcionamiento del **principio de dirección Ackermann**.

---

# Acople de la rueda con la barra derecha

[Link al diseño en Fusion 360](https://a360.co/40ZcX1X)
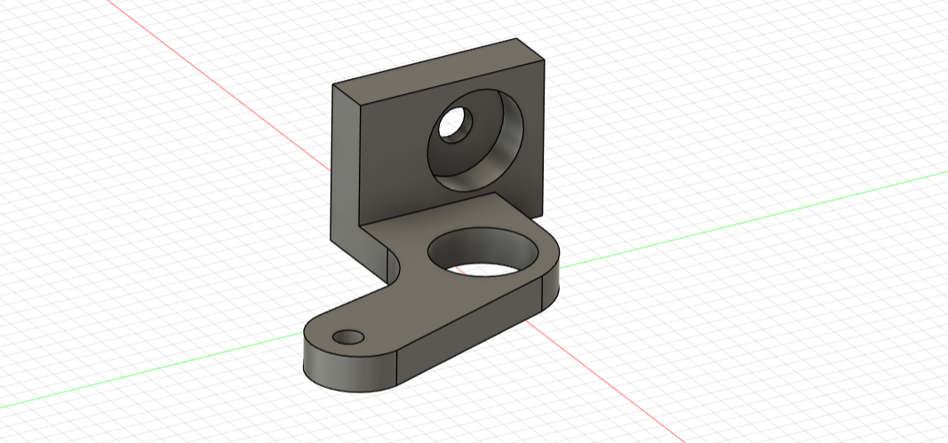
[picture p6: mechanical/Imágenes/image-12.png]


El **acople derecho** conecta la barra de dirección con el soporte de la rueda derecha.

Esta pieza permite transmitir el movimiento de la barra hacia la rueda, permitiendo modificar su orientación durante el giro.

El diseño fue optimizado para permitir:

- Libertad de movimiento.
- Buena transmisión de fuerzas.
- Integración sencilla con el resto del sistema.

---

# Acople de la rueda con la barra izquierda

[Link al diseño en Fusion 360](https://a360.co/4brRZOb)
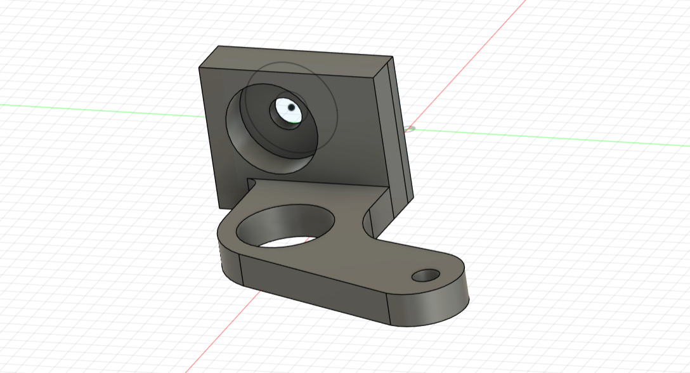
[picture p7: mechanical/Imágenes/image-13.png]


El **acople izquierdo** cumple la misma función que el acople derecho, pero en el lado opuesto del sistema de dirección.

Este componente conecta la barra de dirección con la rueda izquierda, permitiendo que ambas ruedas se orienten correctamente durante los giros del robot.

El diseño de ambas piezas permite mantener la **simetría del sistema de dirección** y asegurar el correcto funcionamiento del mecanismo Ackermann.

---

# Soporte Ackerman a la base

[Link al diseño en Fusion 360](https://a360.co/4lu62Yf)
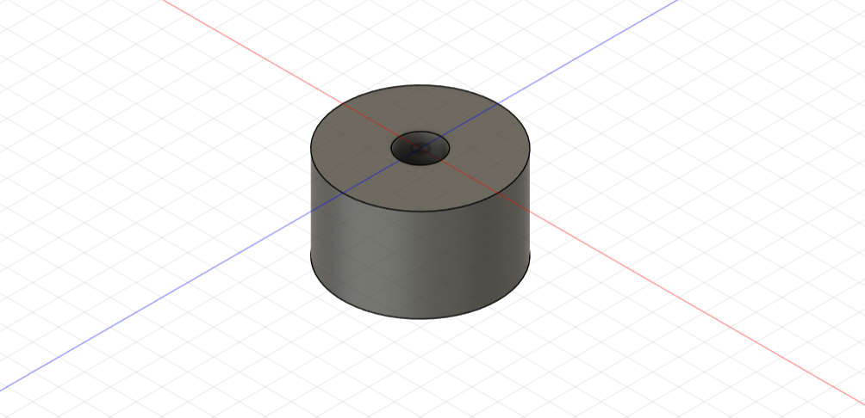
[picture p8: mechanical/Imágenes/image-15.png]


El **soporte del sistema Ackermann** es la pieza encargada de fijar el mecanismo de dirección a la base estructural del robot.

Su función principal es:

- Mantener la posición del sistema de dirección.
- Garantizar la estabilidad del mecanismo.
- Permitir el correcto alineamiento entre las piezas móviles.

Esta pieza actúa como interfaz estructural entre el sistema de dirección y el chasis del robot.

---

# Ensamblaje del sistema de dirección

[Link al diseño en Fusion 360](https://a360.co/3NeH8PA)
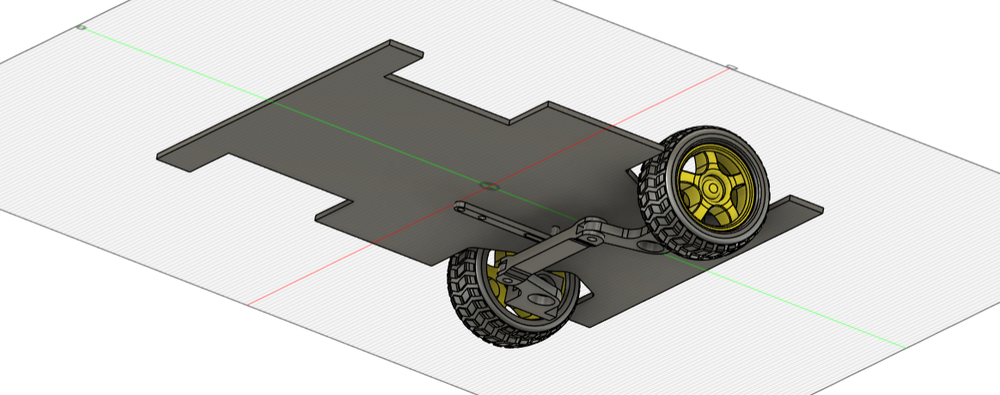
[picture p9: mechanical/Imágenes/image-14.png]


El sistema completo de dirección se obtiene mediante el **ensamblaje de todos los componentes descritos anteriormente**.

En primer lugar, el **servo motor SG90** se fija a la **base de dirección** mediante tornillos. Posteriormente, el **piñón del servo** se conecta al eje del servo y engrana con el **engranaje del brazo de dirección**, permitiendo transmitir el movimiento rotacional.

El **engranaje** se encuentra unido al **brazo de dirección**, el cual convierte el movimiento rotacional en un desplazamiento que acciona la **barra de dirección**.

Esta barra conecta los **acoples de las ruedas izquierda y derecha**, permitiendo que ambas ruedas giren simultáneamente cuando el servo cambia su posición.

Gracias a la geometría del mecanismo, las ruedas describen ángulos diferentes durante los giros, cumpliendo con el **principio de dirección Ackermann**, lo que mejora la estabilidad y reduce el deslizamiento de las ruedas.

El diseño modular del sistema permite **facilitar el ensamblaje, mantenimiento y futuras modificaciones del robot**, ya que cada componente puede ser reemplazado o ajustado sin afectar el resto del mecanismo.

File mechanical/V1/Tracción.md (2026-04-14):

# Tracción

El sistema de tracción del robot fue diseñado utilizando **Autodesk Fusion 360**, con el objetivo de desarrollar un mecanismo de locomoción estable, eficiente y de fácil fabricación para un robot móvil terrestre de pequeña escala orientado a aplicaciones logísticas o de navegación autónoma en entornos interiores como bodegas.

El robot emplea un sistema de **locomoción diferencial**, basado en dos ruedas motrices accionadas de manera independiente por motores con caja reductora. Este tipo de configuración es ampliamente utilizado en robótica móvil debido a su simplicidad mecánica, facilidad de control y buena maniobrabilidad en espacios reducidos.

Para el desplazamiento se seleccionaron **dos motores con caja reductora JGY370**, los cuales proporcionan un equilibrio adecuado entre **velocidad y torque**, permitiendo que el robot pueda desplazarse de manera estable sobre superficies planas y transportar su propia estructura junto con los componentes electrónicos.

Durante el proceso de diseño se modelaron diferentes componentes mecánicos en **Fusion 360**, con el fin de verificar dimensiones, interferencias y correcta integración entre las piezas. Posteriormente, dichos componentes fueron **fabricados mediante tecnologías de fabricación digital**, principalmente **corte láser e impresión 3D**, dependiendo de los requerimientos estructurales de cada pieza.

El conjunto de todos estos elementos conforma el **sistema de tracción del robot**, el cual se integra sobre la base estructural principal del vehículo.

---

## Base_Traccion

[Link al diseño en Fusion 360](https://a360.co/4dkDRIV)
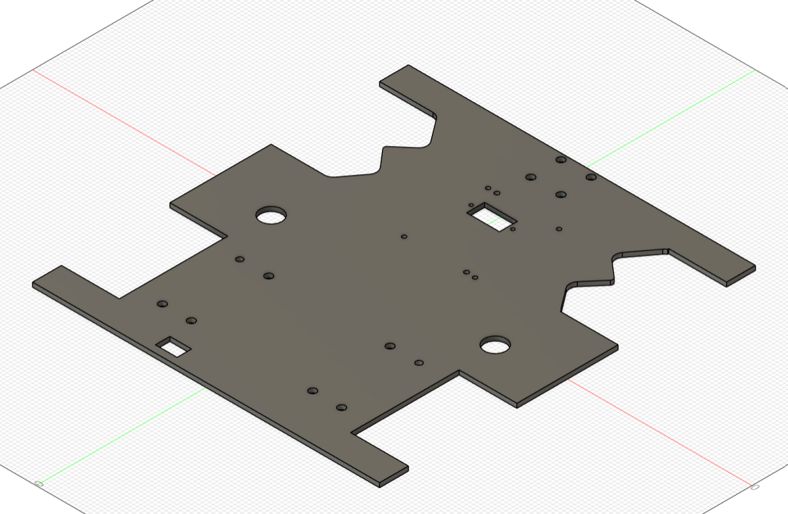
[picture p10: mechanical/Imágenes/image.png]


La **base de tracción** constituye la estructura principal del sistema de locomoción del robot. Sobre esta pieza se montan los motores, soportes estructurales y demás componentes asociados al movimiento.

Durante el diseño de esta pieza se consideraron aspectos como:

- Distribución del peso del robot.
- Distribución de la carga que soportará el robot.
- Ubicación estratégica de los motores.
- Espacio disponible para componentes electrónicos.
- Rigidez estructural necesaria para soportar vibraciones.

El diseño busca garantizar estabilidad mecánica durante el desplazamiento y facilitar el ensamblaje del sistema completo.

La base fue **fabricada mediante corte láser** en madera 4 mm, técnica que facilita la rápida reproducción de la pieza en caso de ser necesario.

---

## GearBox JGY370

[Link al diseño en Fusion 360](https://a360.co/4luaPZA)
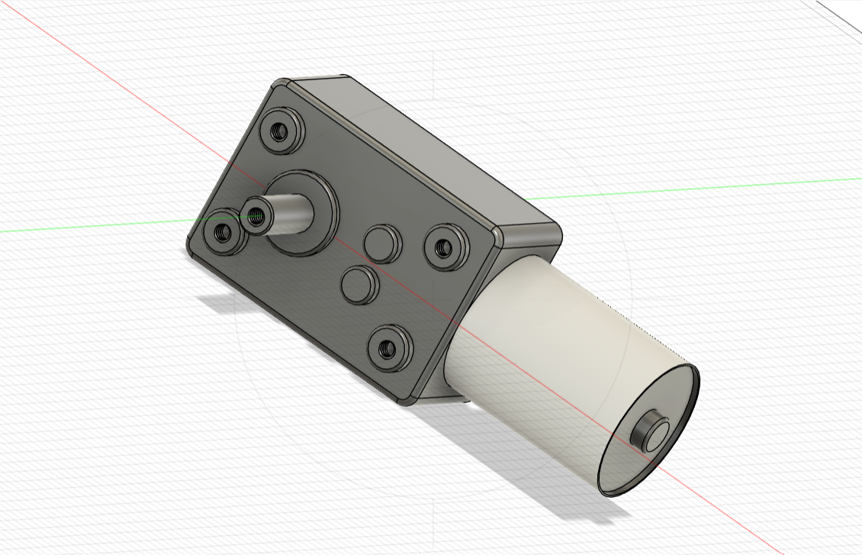
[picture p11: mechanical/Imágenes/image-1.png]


El **motorreductor JGY370** es el encargado de generar el movimiento del robot. Este tipo de motor integra una **caja reductora (gearbox)** que reduce la velocidad de rotación del motor eléctrico mientras incrementa el torque disponible en el eje de salida.

Esta característica resulta especialmente útil en robots móviles, ya que permite:

- Superar la inercia inicial del sistema.
- Mover la estructura del robot con mayor eficiencia.
- Garantizar desplazamientos controlados a baja velocidad y mayor torque.

El motor utilizado corresponde a un **componente comercial**, por lo que no fue diseñado dentro del proyecto. Sin embargo, se incluyó su modelo dentro del entorno CAD con el propósito de **verificar su correcta integración mecánica con el resto del sistema de tracción**.

Esto permitió validar aspectos como alineación, espacio disponible y compatibilidad con los soportes diseñados.

---

## Acople de la llanta al GearBox JGY370

[Link al diseño en Fusion 360](https://a360.co/3NlTGo7)
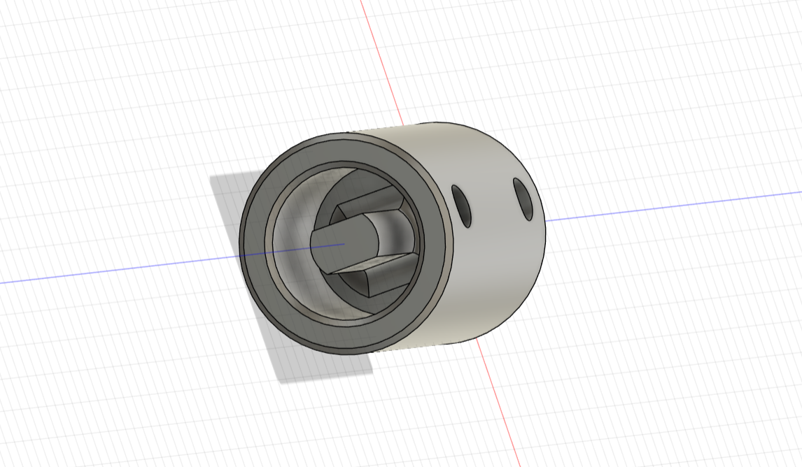
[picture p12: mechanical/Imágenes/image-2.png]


El **acople de la llanta al GearBox JGY370** es la pieza encargada de conectar el eje del motor con la rueda común del sistema de tracción.

Su función principal es **transmitir el movimiento rotacional del motor hacia la rueda de forma eficiente**, evitando pérdidas de torque, desalineaciones o deslizamientos durante el funcionamiento.

El diseño del acople fue realizado considerando:

- El diámetro del eje del motor.
- El sistema de fijación de la rueda.
- La necesidad de mantener una alineación adecuada entre ambos elementos.

Este componente fue **fabricado mediante impresión 3D utilizando filamento PLA**, lo que permitió adaptar con precisión las dimensiones del acople a las características del motor utilizado.

Además, la impresión 3D facilita la fabricación rápida de prototipos y permite realizar ajustes de diseño en caso de ser necesario.

---

## Soporte de motor derecho e izquierdo

[Link al diseño en Fusion 360 del soporte derecho](https://a360.co/4uqkBQr)
[Link al diseño en Fusion 360 del soporte izquierdo](https://a360.co/4lodmnX)
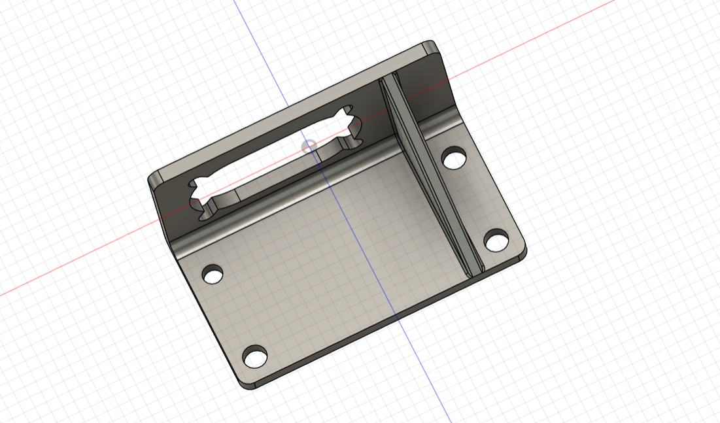
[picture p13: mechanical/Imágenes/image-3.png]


El **soporte de motor derecho e izquierdo** tienen como función fijar cada uno de los motores reductores al chasis del robot, manteniendo su posición y alineación respecto a la rueda correspondiente.

Estos soportes fueron diseñados teniendo en cuenta varios criterios:

- Garantizar la correcta alineación entre el eje del motor y la rueda.
- Proporcionar una fijación rígida que reduzca vibraciones durante el movimiento.
- Permitir un montaje y desmontaje sencillo del motor en caso de mantenimiento.

La pieza fue **fabricada mediante impresión 3D en filamento PLA**, lo que permitió desarrollar una geometría adaptada específicamente al motor y al espacio disponible dentro del robot.

---

## Rueda común (Wheel)

[Link al diseño en Fusion 360](https://a360.co/47i5jn9)
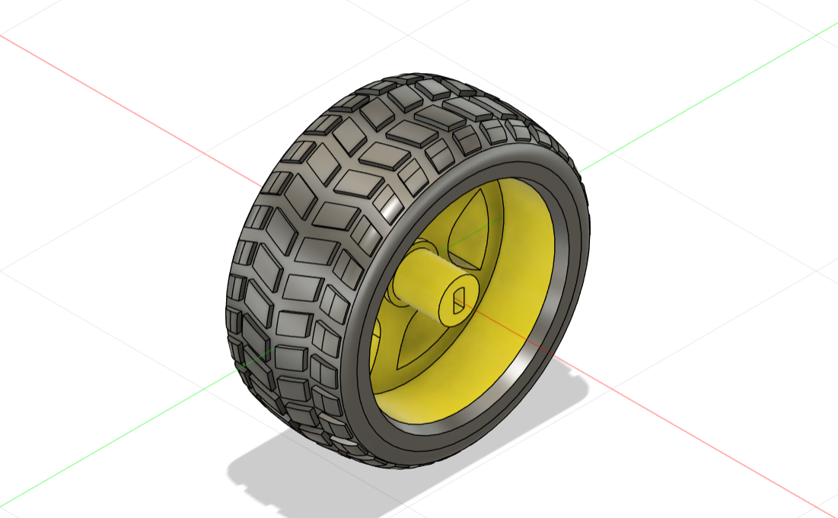
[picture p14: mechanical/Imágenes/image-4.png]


La **rueda del sistema de tracción** es el elemento encargado de transformar el movimiento rotacional generado por el motor en **desplazamiento lineal del robot sobre la superficie**.

Este componente corresponde a una **rueda comercial**, por lo que no fue diseñada ni fabricada dentro del proyecto.

No obstante, dentro del modelo CAD se incluyó una **representación escalada de la rueda**, con el objetivo de:

- Verificar dimensiones.
- Detectar posibles interferencias con otras piezas.
- Validar la correcta integración con el sistema de tracción.

Esta práctica es común dentro del diseño mecánico asistido por computador, ya que permite evaluar el comportamiento del sistema antes de su fabricación física.

---

## Soporte LiPo

[Link al diseño en Fusion 360](https://a360.co/4uqY3Pr)
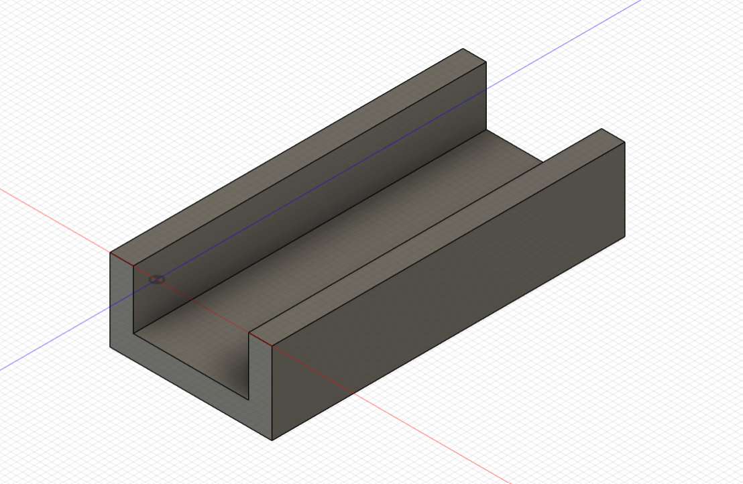
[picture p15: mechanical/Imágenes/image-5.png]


El **soporte para la batería LiPo** fue diseñado con el objetivo de alojar de forma segura la batería encargada de alimentar el sistema eléctrico del robot.

La correcta ubicación de la batería es un aspecto importante dentro del diseño del robot, ya que influye directamente en la **distribución del peso y en la estabilidad del sistema durante el desplazamiento**. Esta ubicación fue definida para que la bateria lipo se aloje entre los soporte de los motores.

El diseño del soporte busca cumplir las siguientes funciones:

- Mantener la batería fija durante el movimiento del robot.
- Evitar desplazamientos o vibraciones que puedan afectar los componentes electrónicos.
- Permitir un acceso sencillo para tareas de mantenimiento o reemplazo.

Este soporte será **fabricado mediante corte de madera 4 mm**.

---

## Ensamblaje del sistema de tracción

[Ensamblaje del sistema de tracción](https://a360.co/3P7TtFJ)
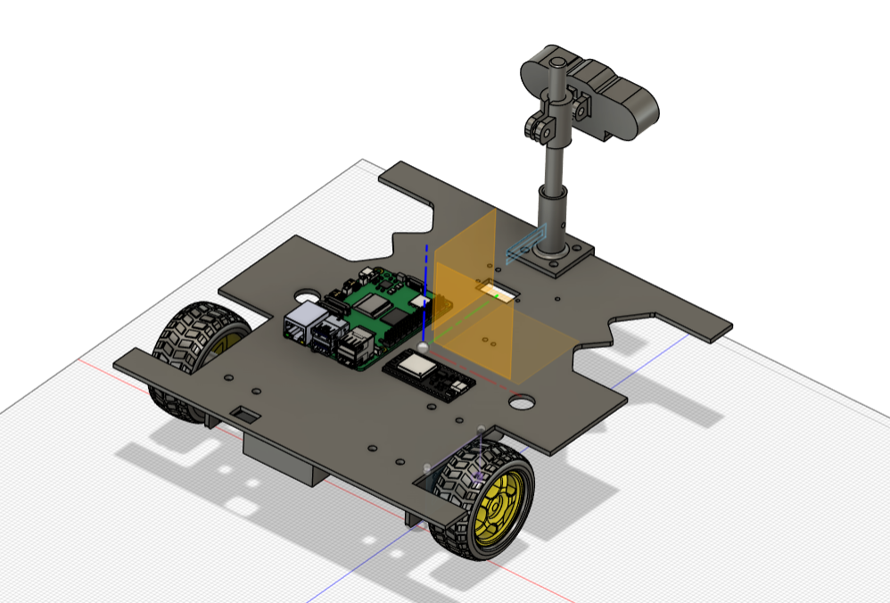
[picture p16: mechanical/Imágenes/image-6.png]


El sistema completo de tracción se obtiene mediante el **ensamblaje de todos los componentes descritos anteriormente**.

En primer lugar, los motores JGY370 se fijan a la base estructural utilizando los soportes impresos en 3D. Posteriormente, los acoples diseñados permiten conectar el eje de cada motor con su respectiva rueda, garantizando una transmisión eficiente del movimiento.

Este sistema permite implementar un esquema de **locomoción diferencial**, en el cual cada motor puede ser controlado de manera independiente. Gracias a este principio de funcionamiento, el robot puede realizar diferentes tipos de movimiento, tales como:

- Avance en línea recta.
- Retroceso.
- Giros sobre su propio eje.
- Curvas con diferentes radios de giro.

El diseño modular del sistema de tracción facilita tanto el **proceso de fabricación como el mantenimiento del robot**, ya que cada componente puede ser reemplazado o modificado sin afectar el resto de la estructura.

Esto permite realizar mejoras futuras en el sistema de locomoción sin necesidad de rediseñar completamente el robot.

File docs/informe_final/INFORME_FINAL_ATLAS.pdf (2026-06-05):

ATLAS - Informe Final | 1

ATLAS: Robot móvil autónomo para procesos de carga y descarga en entornos logísticos

controlados

Informe Final

Vanesa Galeano Franco, Jose Lisander Hurtado Castañeda, Julián Andrés García Correa y

Sofia Salome Espitia Jiménez

Informe Final de las Asignaturas: Proyecto Integrador I & II y Formación Integral

Universidad Tecnológica de Pereira

Facultad de Tecnología

Programa de Ingeniería Mecatrónica

Pereira, Colombia

2026

ATLAS - Informe Final | 2

Resume

El presente proyecto desarrolla un robot móvil autónomo denominado ATLAS para procesos de

carga y descarga en entornos logísticos controlados. El sistema implementa una arquitectura

distribuida basada en Raspberry Pi 5 y ESP32, donde la Raspberry Pi ejecuta algoritmos de

visión artificial y navegación, mientras que el ESP32 controla el sistema de locomoción

mediante señales PWM. El robot incorpora un mecanismo de dirección tipo Ackermann, motores

JGY370 de 6V y un driver TB6612FNG para el control de movimiento. Asimismo, se integró

una cámara IMX219 y algoritmos desarrollados en Python y OpenCV para el reconocimiento de

códigos QR y el seguimiento de trayectoria en tiempo real. El desarrollo se realizó bajo la

metodología de Aprendizaje Basado en Proyectos (ABP), incluyendo diseño mecánico,

integración electrónica, programación y validación experimental. Las pruebas funcionales

realizadas sobre una pista controlada permitieron validar el seguimiento de línea, el

reconocimiento de códigos QR y la detención automática en estaciones de carga y descarga. Los

resultados obtenidos evidencian la integración funcional de sistemas embebidos, visión artificial

y navegación autónoma en una plataforma robótica aplicada a la automatización logística

académica.

Palabras Clave: robot móvil autónomo, visión artificial, navegación autónoma, códigos

QR, Raspberry Pi 5, ESP32.

ATLAS - Informe Final | 3

Abstract

This project involves the development of an autonomous mobile robot called ATLAS for use in

the loading and unloading of goods in controlled logistics environments. The system has a

distributed architecture based on Raspberry Pi 5 and ESP32. The Raspberry Pi runs computer

vision and navigation algorithms, while the ESP32 controls the locomotion system via pulse

width modulation (PWM) signals. The robot incorporates an Ackermann-type steering

mechanism and 6 V JGY370 motors, as well as a TB6612FNG driver, to control its motion. It

also incorporates an IMX219 camera and Python and OpenCV algorithms for QR code

recognition and real-time trajectory tracking. The project was developed using the Project-Based

Learning (PBL) methodology, incorporating mechanical design, electronic integration,

programming, and experimental validation. Functional tests conducted on a controlled track

verified the functionality of line tracking, QR code recognition and automatic stopping at loading

and unloading stations. These results demonstrate the successful integration of embedded

systems, machine vision and autonomous navigation in an academic logistics automation robotic

platform.

Keywords: autonomous mobile robot, computer vision, autonomous navigation, QR codes,

Raspberry Pi 5, ESP32.

ATLAS - Informe Final | 4

Tabla De Contenido

Resumen | 2
Abstract | 3
Tabla de Contenido | 4
Tabla De Figuras | 6
1. Introducción | 7
2. Planteamiento Del Problema | 8
3. Objetivos | 9
3.1 Objetivo General | 9
3.2 Objetivos Específicos | 9
4. Justificación | 10
5. Marco Teórico | 12
3.1 Robots móviles autónomos | 12
3.2 Navegación autónoma y control | 13
3.3 Visión artificial y reconocimiento de códigos QR | 13
3.4 Dirección tipo Ackerman | 14
3.5 Automatización logística e Industrial 4.0 | 14

ATLAS - Informe Final | 5
6. Metodología | 15
6.1 Tipo de investigación | 15
6.2 Enfoque metodológico | 16
6.3 Actividades y metodología | 16
6.4 Cronograma de actividades | 17
6.5 Presupuesto y recursos | 19
7. Resultados | 21
8. Conclusiones | 27
Referencias | 29
Anexos | 31

ATLAS - Informe Final | 6

Tabla De Figuras

Figura 1 Cronograma de actividades | 18
Figura 2 Presupuesto del proyecto | 20
Figura 3 Vista superior del robot | 21
Figura 4 Sistema de tracción y dirección | 22
Figura 5 Arquitectura electrónica | 23
Figura 6 Reconocimiento de códigos QR | 24
Figura 7 Seguimiento de línea | 25
Figura 8 Robot en la estación de carga | 26

Introducción

La automatización de procesos logísticos ha tomado gran relevancia en los últimos años

debido a la necesidad de optimizar tareas de transporte, distribución y almacenamiento dentro de

entornos industriales. En este contexto, los robots móviles autónomos representan una solución

tecnológica capaz de mejorar la eficiencia operativa, reducir tiempos de trabajo y minimizar la

intervención humana en actividades repetitivas o de riesgo. Gracias al avance de áreas como la

visión artificial, los sistemas embebidos y el control inteligente, actualmente es posible

desarrollar plataformas robóticas con capacidades de navegación autónoma y toma de decisiones

en tiempo real.

El robot autónomo ATLAS surge como una propuesta orientada al desarrollo de un robot

móvil autónomo capaz de operar en un entorno logístico controlado, realizando tareas de carga,

transporte y descarga mediante navegación autónoma y reconocimiento de códigos QR. El

sistema integra una arquitectura distribuida basada en Raspberry Pi 5 y ESP32, combinando

procesamiento de visión artificial en Python con OpenCV, control de motores mediante señales

PWM y un mecanismo de dirección tipo Ackermann para mejorar la estabilidad y

maniobrabilidad del robot.

El desarrollo del proyecto se llevó a cabo bajo la metodología de Aprendizaje Basado en

Proyectos (ABP), integrando conocimientos de diseño mecánico, electrónica, programación y

control. Para ello, se realizaron procesos de modelado CAD, fabricación de componentes

mediante impresión 3D, integración electrónica y desarrollo de algoritmos de navegación y

percepción visual. Asimismo, se ejecutaron pruebas funcionales para validar el desempeño del

sistema en tareas de seguimiento de trayectoria, detección de obstáculos y control autónomo del

robot.

Planteamiento Del Problema

En los entornos logísticos y de almacenamiento, los procesos de transporte, carga y

descarga aún dependen en gran medida de sistemas con limitada autonomía y capacidad de

adaptación. Aunque los robots móviles autónomos han permitido avanzar en la automatización

industrial, todavía existen limitaciones relacionadas con la integración de navegación autónoma,

percepción del entorno y toma de decisiones en tiempo real, afectando la eficiencia y precisión

de los procesos logísticos (Siegwart et al., 2019).

Asimismo, la implementación de sistemas de visión artificial y comunicación distribuida

entre dispositivos de control representa un desafío técnico debido a la necesidad de garantizar

estabilidad, respuesta rápida y coordinación entre los diferentes componentes del sistema

(Arrichiello et al., 2017). En el contexto de la Industria 4.0, tecnologías como visión artificial,

reconocimiento de códigos QR y arquitecturas basadas en microcontroladores han fortalecido el

desarrollo de soluciones autónomas aplicadas a procesos de almacenamiento y distribución

(Ellithy et al., 2024).

Sin embargo, el diseño de plataformas robóticas que integren mecánica, electrónica y

software de manera eficiente continúa siendo un reto en proyectos de automatización móvil,

especialmente en sistemas que requieren desplazamiento autónomo, detección de obstáculos y

ejecución de tareas en tiempo real. Además, la necesidad de optimizar recursos, reducir tiempos

de operación y mejorar la seguridad dentro de entornos industriales impulsa el desarrollo de

soluciones robóticas capaces de operar de manera autónoma y confiable.

Como respuesta a estas problemáticas y a la necesidad de fortalecer los procesos de

automatización logística mediante sistemas autónomos, surge el interés por desarrollar un robot

autónomo. En este contexto, se plantea la siguiente pregunta de investigación:

¿Cómo desarrollar un robot móvil autónomo capaz de integrar navegación, visión

artificial y toma de decisiones en tiempo real para optimizar procesos de carga y descarga

en entornos logísticos controlados?

PREGUNTAS ORIENTADORAS

- ¿Cómo diseñar un sistema mecánico que garantice estabilidad y maniobrabilidad en

el robot autónomo?

- ¿Cómo integrar la comunicación entre la Raspberry Pi y el ESP32 para el control

del sistema?

- ¿Cómo implementar visión artificial para el reconocimiento de códigos QR y la

navegación autónoma?

Objetivos

Objetivo General

Construir un robot móvil autónomo con tracción tipo Ackermann, ruedas comunes y una

arquitectura de control que consta de Raspberry Pi 5 y ESP32, capaz de transportar una carga de

hasta 1 kg mediante navegación autónoma y reconocimiento de códigos QR utilizando visión

artificial con la cámara IMX219, durante el periodo académico 20261.

Objetivos Específicos

- Diseñar un sistema de tracción con dos motores JGY370 de 6V controlados

mediante el driver Pololu TB6612FNG y un mecanismo de dirección tipo Ackermann que

garantice estabilidad y maniobrabilidad bajo una carga de 1 kg, con un plazo máximo para la

semana 6.

- Programar el ESP32 para el control de los motores mediante señales PWM

enviadas al driver TB6612FNG y establecer comunicación serial bidireccional con la Raspberry

Pi 5 para la recepción de comandos y el envío de información de estado del sistema, con un

plazo máximo para la semana 7.

- Desarrollar e implementar en la Raspberry Pi 5 un algoritmo en Python para el

reconocimiento de códigos QR mediante la cámara IMX219, generando comandos de

navegación que serán enviados al ESP32 para la ejecución del movimiento correspondiente, con

un plazo máximo para la semana 8.

- Validar el sistemas mecánico, electrónico y de control del robot, verificando la

correcta comunicación entre la Raspberry Pi 5 y el ESP32, el funcionamiento del sistema de

tracción y dirección tipo Ackermann, y la ejecución coordinada del sistema de visión y

navegación autónoma, con un plazo máximo para la semana 14.

Justificación

El desarrollo de robots móviles autónomos representa una de las principales áreas de

crecimiento dentro de la automatización industrial y logística, debido a su capacidad para

optimizar procesos de transporte, almacenamiento y distribución. En la actualidad, las empresas

buscan implementar soluciones tecnológicas que permitan aumentar la eficiencia operativa,

reducir tiempos de trabajo y minimizar riesgos asociados a tareas repetitivas o de supervisión

constante. En este contexto, la integración de sistemas de navegación autónoma, visión artificial

y control inteligente se ha convertido en una herramienta fundamental para el desarrollo de

plataformas robóticas aplicadas a entornos industriales (Ellithy et al., 2024; Yarlagadda, 2024).

El proyecto ATLAS surge como una propuesta orientada al diseño y construcción de un

robot móvil autónomo capaz de ejecutar tareas de carga y descarga dentro de un entorno logístico

controlado. La importancia del proyecto radica en la integración de conocimientos de mecánica,

electrónica y programación para el desarrollo de un sistema autónomo que combine percepción del entorno, toma de decisiones y desplazamiento eficiente. Además, la implementación de

tecnologías como Raspberry Pi 5, ESP32, visión artificial mediante OpenCV y reconocimiento

de códigos QR permite fortalecer competencias relacionadas con sistemas embebidos,

automatización y robótica móvil (Bradski, 2000; Rodríguez).

De igual manera, el proyecto contribuye al fortalecimiento académico y tecnológico en

áreas asociadas a la Industria 4.0, promoviendo el desarrollo de soluciones aplicables a procesos

logísticos automatizados. Según Siegwart et al. (2019), los robots móviles autónomos

constituyen una alternativa eficiente para la optimización de tareas industriales gracias a su

capacidad de adaptación y navegación en tiempo real. Asimismo, la implementación de

arquitecturas distribuidas de control mejora la estabilidad y coordinación entre los diferentes

componentes del sistema robótico (Arrichiello et al., 2017).

Desde el ámbito académico, el desarrollo del proyecto permite aplicar de manera práctica

los conocimientos adquiridos en áreas como diseño mecánico, electrónica, programación, control

y visión artificial, fortaleciendo competencias técnicas y profesionales fundamentales en la

formación mecatrónica. La construcción de un prototipo funcional favorece además el

aprendizaje basado en proyectos, promoviendo el trabajo interdisciplinario, la resolución de

problemas y la integración de diferentes tecnologías dentro de un mismo sistema autónomo

(Siciliano & Khatib, 2016).

Adicionalmente, el proyecto tiene potencial de aplicación en sistemas de automatización

logística, robótica educativa y futuras investigaciones relacionadas con navegación autónoma y

percepción artificial. La integración de algoritmos de control, detección de obstáculos y

reconocimiento visual permite establecer una base tecnológica adaptable a nuevos desarrollos en

vehículos autónomos y sistemas inteligentes de transporte. De esta manera, ATLAS no solo aporta al desarrollo académico, sino también al fortalecimiento de soluciones tecnológicas

orientadas a la transformación digital y automatización de procesos industriales.

Marco Teórico

El presente marco teórico aborda los principales conceptos y fundamentos tecnológicos

relacionados con el desarrollo de robots móviles autónomos aplicados a procesos de

automatización logística. Para ello, se presentan aspectos asociados a navegación autónoma,

sistemas de control, visión artificial, dirección Ackermann y automatización industrial, los cuales

constituyen la base teórica y técnica para el desarrollo del proyecto ATLAS.

Robots Móviles Autónomos

Los robots móviles autónomos son sistemas diseñados para desplazarse e interactuar con

su entorno sin intervención humana directa, utilizando sensores, sistemas de control y algoritmos

de navegación para ejecutar tareas de manera autónoma. Según Siegwart, Nourbakhsh y

Scaramuzza (2019), estos robots integran procesos de percepción, localización, planificación de

trayectorias y control de movimiento, permitiendo adaptarse dinámicamente a diferentes

entornos de operación.

En aplicaciones industriales y logísticas, los robots móviles autónomos han adquirido

gran importancia debido a su capacidad para optimizar procesos de transporte, almacenamiento y

distribución de materiales. Su implementación permite reducir tiempos operativos, minimizar

errores humanos y mejorar la eficiencia en tareas repetitivas dentro de bodegas y centros de

distribución. Además, el desarrollo de nuevas tecnologías en sensores, microcontroladores y

sistemas embebidos ha impulsado el crecimiento de plataformas robóticas cada vez más precisas

y accesibles para aplicaciones académicas e industriales.

Navegación Autónoma y Control

La navegación autónoma corresponde a la capacidad que posee un robot para desplazarse

de forma independiente dentro de un entorno, tomando decisiones en tiempo real a partir de la

información obtenida mediante sensores y sistemas de percepción. Para ello, los robots emplean

algoritmos de control y planificación de trayectorias que permiten definir rutas, evitar obstáculos

y mantener estabilidad durante el movimiento (Zhang et al. 2023) .

Dentro de los sistemas de navegación autónoma, el control de motores desempeña un

papel fundamental, ya que permite regular velocidad, dirección y precisión de desplazamiento.

Una de las técnicas más utilizadas es el control mediante señales PWM (Pulse Width

Modulation), ampliamente implementado en motores DC debido a su eficiencia y facilidad de

integración con microcontroladores. Asimismo, las arquitecturas distribuidas basadas en

dispositivos como Raspberry Pi y ESP32 permiten dividir tareas de procesamiento y control,

mejorando el desempeño y la capacidad de respuesta del sistema robótico (Arrichiello et al.,

2017).

Visión Artificial y Reconocimiento de Códigos QR

La visión artificial es una rama de la inteligencia artificial enfocada en el procesamiento e

interpretación de imágenes y video para la identificación de objetos, patrones y características

del entorno. En robótica móvil, esta tecnología permite que los robots puedan reconocer rutas,

detectar obstáculos y tomar decisiones de navegación a partir de información visual.

De acuerdo con Bradski (2000), OpenCV es una de las bibliotecas más utilizadas para el

desarrollo de aplicaciones de visión computacional, ya que proporciona herramientas para

procesamiento de imágenes, detección de bordes, reconocimiento de patrones y seguimiento de

objetos en tiempo real. En aplicaciones logísticas, el reconocimiento de códigos QR se ha convertido en una alternativa eficiente para identificación de rutas, estaciones o instrucciones

dentro de sistemas automatizados. Estos códigos permiten almacenar información de manera

rápida y accesible, facilitando procesos de navegación y control autónomo dentro de plataformas

robóticas.

Además, el uso de cámaras integradas y algoritmos de procesamiento visual permite

mejorar la interacción del robot con el entorno, fortaleciendo la precisión de desplazamiento y la

capacidad de respuesta frente a cambios en el ambiente de operación.

Dirección Tipo Ackermann

La dirección tipo Ackermann es un mecanismo de dirección utilizado principalmente en

vehículos terrestres para mejorar la maniobrabilidad durante el desplazamiento en curvas. Este

sistema se basa en un principio geométrico que permite que las ruedas delanteras giren con

diferentes ángulos, reduciendo el deslizamiento y mejorando la estabilidad del vehículo.

Según Siciliano y Khatib (2016), la geometría Ackermann es ampliamente utilizada en

robots móviles y vehículos autónomos debido a que optimiza el control de trayectoria y

disminuye el desgaste mecánico de las ruedas durante el movimiento. Su implementación resulta

especialmente útil en plataformas robóticas que requieren desplazamientos precisos y estables

dentro de entornos controlados.

Asimismo, la integración de sistemas de dirección Ackermann con motores DC y

servomotores permite obtener un mejor control del movimiento del robot, facilitando la

ejecución de maniobras y el seguimiento de trayectorias previamente definidas.

Automatización Logística e Industria 4.0

La automatización logística consiste en la incorporación de tecnologías inteligentes para

optimizar procesos de almacenamiento, transporte y distribución dentro de entornos industriales.

En el contexto de la Industria 4.0, la integración de robots móviles autónomos, sistemas de visión

artificial y comunicación inalámbrica ha permitido desarrollar soluciones más eficientes y

flexibles para la gestión logística (Ellithy et al., 2024).

La Industria 4.0 busca integrar tecnologías digitales, automatización y sistemas

inteligentes para mejorar la productividad y adaptabilidad de los procesos industriales. Dentro de

este enfoque, los robots autónomos representan una herramienta clave debido a su capacidad

para operar de manera continua, interpretar información del entorno y ejecutar tareas con mínima

intervención humana.

Además, la implementación de sistemas autónomos en logística contribuye a reducir

costos operativos, optimizar tiempos de trabajo y mejorar la seguridad en procesos de transporte

de materiales. Por esta razón, el desarrollo de plataformas robóticas móviles se ha convertido en

una de las principales áreas de investigación y aplicación dentro de la ingeniería y

automatización industrial.

Metodología

El desarrollo del proyecto se llevó a cabo mediante una metodología de enfoque práctico

y aplicado, orientada al diseño e implementación de un robot móvil autónomo para entornos

logísticos controlados. La metodología integró procesos de diseño mecánico, electrónica,

programación y validación funcional, permitiendo el desarrollo progresivo del sistema robótico.

Tipo de Investigación

El proyecto se desarrolló bajo un enfoque de investigación aplicada y experimental,

orientado al diseño e implementación de un robot móvil autónomo para automatización logística

en entornos controlados. La investigación aplicada permitió integrar conocimientos de mecánica,

electrónica y programación para el desarrollo de una solución funcional, mientras que el enfoque experimental se centró en la realización de pruebas de navegación, control y percepción del

entorno.

Enfoque Metodológico

La metodología empleada se basó en el Aprendizaje Basado en Proyectos (ABP),

permitiendo el desarrollo progresivo del sistema robótico mediante etapas de diseño, fabricación,

integración y validación. El proyecto se estructuró a partir de procesos iterativos de prueba y

mejora continua, facilitando la corrección de errores mecánicos, electrónicos y de programación

durante el desarrollo del prototipo.

Asimismo, se estableció una planificación por fases organizada mediante cronogramas de

actividades, permitiendo realizar seguimiento al avance del proyecto y controlar procesos de

diseño, fabricación, programación e integración del sistema.

Actividades y Metodología

Tabla 1

Actividades y metodología implementada para el desarrollo del robot autónomo ATLAS.

Objetivos Específicos Actividades
desarrolladas

Descripción
metodológica

Técnicas e
instrumentos

Diseñar un sistema de
tracción y dirección
tipo Ackermann que
garantice estabilidad
y maniobrabilidad del
robot.
Diseño | de
acoples | y
soportes.
Diseño del
mecanismo
Ackermann.
Diseño del chasis.
Impresión 3D de
componentes.
Ensamblaje
estructural del
robot.

Se realizó el modelado
CAD de la estructura y
componentes mecánicos
del robot, seguido de
procesos de fabricación
mediante impresión 3D y
corte | láser para la
construcción | y
ensamblaje del sistema
mecánico.

Fusion 360.
Impresora 3D de
resina.
Corte láser.
Tornillería | y
herramientas
manuales.

Programar el ESP32
para el control de

Conexión de
motores al driver

Se implementó el sistema
de control embebido para

ESP32.
Driver TB6612FNG.

motores y establecer
comunicación serial
con la Raspberry Pi
5.

TB6612FNG.
Configuración
PWM en ESP32.
Pruebas de
velocidad.
Configuración de
comunicación
serial
bidireccional.

el manejo de motores DC
y comunicación serial
entre dispositivos,
permitiendo la recepción
y ejecución de comandos
de navegación.

Visual Studio Code.
Programación en
C++.

Desarrollar un
algoritmo en Python
para reconocimiento
de códigos QR y
navegación
autónoma.

Conexión de
cámara IMX219.
Instalación de
librerías.
Procesamiento de
imágenes y
lectura QR.
Envío | de
comandos | al
ESP32.
Se | desarrollaron
algoritmos | de visión
artificial para detección
de | códigos | QR | y
generación de comandos
de navegación autónoma
mediante procesamiento
de imágenes en tiempo
real.

Raspberry Pi 5.
Python.
OpenCV.
Cámara IMX219.
Validar | el
funcionamiento
mecánico, electrónico
y de control del robot
autónomo.

Evaluación de
estabilidad.
Verificación de
alimentación
eléctrica.
Pruebas de
comunicación.
Validación de
navegación
autónoma.

Se realizaron pruebas
funcionales en una pista
controlada con carriles,
estaciones y códigos QR
para validar estabilidad,
navegación y respuesta
del sistema autónomo.

Pista de pruebas.
Sensor ultrasónico
HC-SR04.
Batería LiPo 7.4V.
Instrumentos | de
medición | y
validación.

Nota. La tabla presenta la relación entre los objetivos específicos, las actividades desarrolladas,

la metodología implementada y las herramientas utilizadas durante el desarrollo del robot

autónomo ATLAS. Elaboración propia (2026).

Cronograma de Actividades

Con el fin de garantizar el cumplimiento de los objetivos planteados para el desarrollo del

robot autónomo ATLAS, se estableció un cronograma de trabajo organizado en fases de diseño,

integración, programación, validación y documentación. La planeación permitió realizar seguimiento continuo a las actividades desarrolladas durante el semestre académico, facilitando

la distribución de tareas, el control de avances y la identificación temprana de posibles retrasos.

El cronograma fue estructurado para un periodo de dieciséis semanas, iniciando con

actividades de investigación y definición de requerimientos, seguido del diseño mecánico y

electrónico del sistema, la integración de componentes, el desarrollo de algoritmos de control y

visión artificial, y finalmente las pruebas funcionales y validación del prototipo.

Asimismo, la organización temporal del proyecto permitió integrar progresivamente las

diferentes áreas de trabajo asociadas al sistema robótico, incluyendo diseño CAD, impresión 3D,

programación en Python y C++, integración electrónica y validación experimental sobre la pista

de pruebas.

Figura 1

Cronograma de actividades.

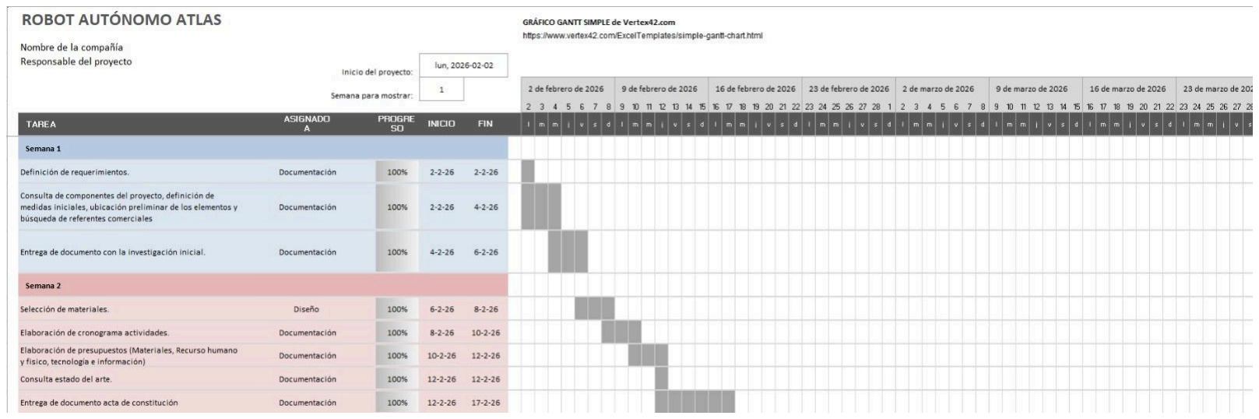
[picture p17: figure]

Nota. El cronograma presenta la distribución temporal de las actividades desarrolladas durante

las etapas de diseño mecánico, integración electrónica, programación, validación y

documentación del proyecto. Debido a la extensión de la tabla original, el cronograma completo puede consultarse en el Anexo A mediante el hipervínculo correspondiente. Elaboración propia

(2026).

Presupuesto y Recursos

Para el desarrollo del robot autónomo ATLAS fue necesario realizar una planificación de

recursos orientada a garantizar la integración mecánica, electrónica y computacional del sistema.

El presupuesto contempló la adquisición de componentes de control, procesamiento,

locomoción, alimentación eléctrica y comunicación, además de materiales complementarios

requeridos para la fabricación y ensamblaje del prototipo.

Entre los principales componentes implementados se encuentran la Raspberry Pi 5 como

unidad principal de procesamiento, el microcontrolador ESP32 para el control embebido, la

cámara IMX219 para visión artificial, los motores JGY370, el driver TB6612FNG y los módulos

de regulación y alimentación eléctrica. Adicionalmente, se utilizaron elementos mecánicos,

conectores, cableado y accesorios necesarios para garantizar la estabilidad estructural y funcional

del robot.

La estimación presupuestal permitió llevar control de costos durante el desarrollo del

proyecto y verificar la viabilidad técnica y económica del sistema autónomo. Asimismo, el

registro de materiales facilitó la trazabilidad de los recursos utilizados durante las etapas de

construcción, integración y validación del prototipo.

Figura 2

Presupuesto del proyecto.

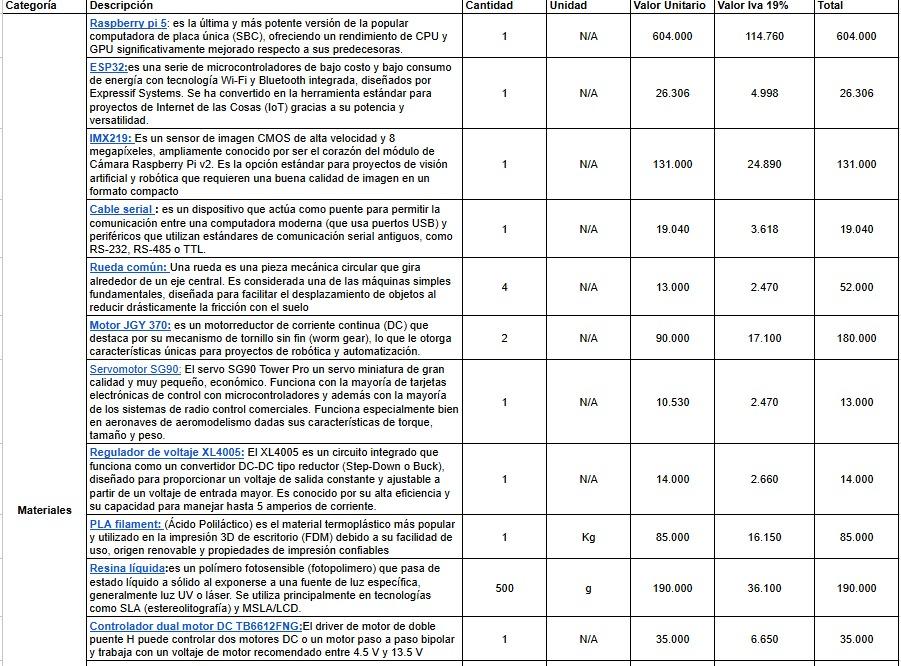
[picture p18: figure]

Nota. La figura presenta una síntesis de los principales recursos y componentes utilizados

durante el desarrollo del proyecto, incluyendo sistemas de procesamiento, control, locomoción y

alimentación eléctrica. El presupuesto detallado completo puede consultarse en el Anexo B

mediante el hipervínculo correspondiente. Elaboración propia (2026).

De acuerdo con el consolidado presupuestal, los principales costos del sistema estuvieron

asociados a la Raspberry Pi 5, la cámara IMX219 y los componentes de locomoción y control

electrónico, debido a que constituyen la base tecnológica necesaria para la navegación autónoma

y el procesamiento de visión artificial.

Resultados

El desarrollo del proyecto permitió construir e implementar un robot móvil autónomo

capaz de desplazarse dentro de una pista controlada mediante navegación asistida por visión

artificial y reconocimiento de códigos QR. La integración de los sistemas mecánico, electrónico

y computacional posibilitó el cumplimiento progresivo de los objetivos planteados durante la

planificación del proyecto.

En la etapa mecánica se logró diseñar y ensamblar un chasis funcional con dirección tipo

Ackermann, permitiendo mejorar la estabilidad y maniobrabilidad del robot durante trayectorias

rectas y curvas. La fabricación de componentes mediante impresión 3D y corte láser permite

adaptar la estructura del robot a las dimensiones y requerimientos definidos para la pista de

pruebas.

Figura 3

Vista superior del robot.

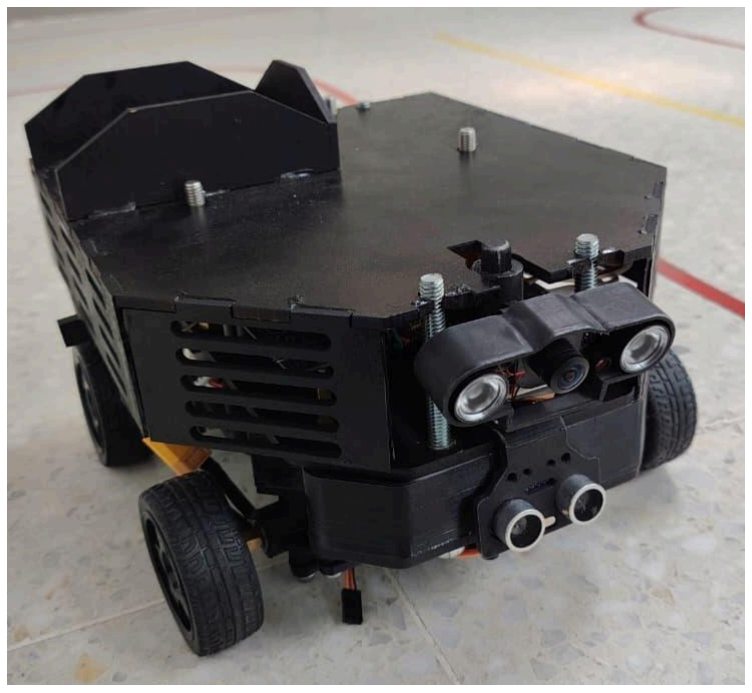
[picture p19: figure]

Nota. La figura presenta la vista superior del robot autónomo ATLAS, donde se observa la

integración general del chasis, la distribución de los componentes electrónicos y la plataforma

principal utilizada para el procesamiento y control del sistema durante las pruebas de navegación

autónoma. Elaboración propia (2026).

Figura 4

Sistema de tracción y dirección.

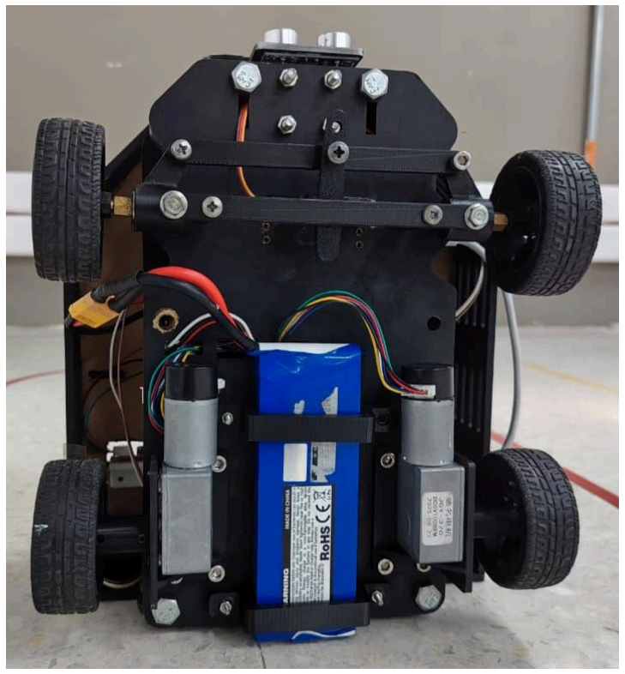
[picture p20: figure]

Nota. La figura muestra la vista inferior del robot autónomo ATLAS, permitiendo evidenciar el

sistema de tracción trasera mediante motores JGY370 y la implementación del mecanismo de

dirección tipo Ackermann. Asimismo, se observa la integración mecánica utilizada para

garantizar estabilidad y maniobrabilidad durante el desplazamiento sobre la pista de validación.

Elaboración propia (2026).

Desde el componente electrónico, se implementó una arquitectura distribuida basada en

Raspberry Pi 5 y ESP32, estableciendo comunicación serial bidireccional entre ambos

dispositivos. Esta integración permitió separar las tareas de procesamiento de visión artificial y

control de motores, mejorando la respuesta del sistema durante la ejecución de comandos de

navegación.

Figura 5

Arquitectura electrónica.

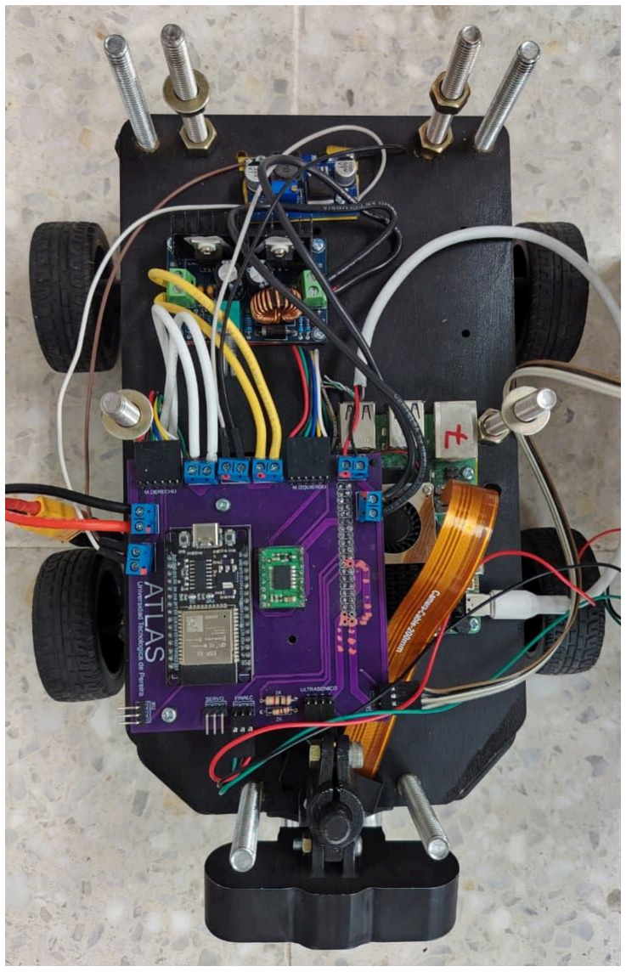
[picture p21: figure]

Nota. La arquitectura electrónica implementada integra una Raspberry Pi 5 encargada del

procesamiento de visión artificial y un ESP32 destinado al control de motores y actuadores. La

comunicación serial bidireccional permitió coordinar el procesamiento de datos y la ejecución de

movimientos durante la navegación autónoma. Elaboración propia (2026).

Asimismo, se desarrolló un algoritmo en Python utilizando OpenCV para el

reconocimiento de códigos QR mediante la cámara IMX219. El sistema fue capaz de detectar

correctamente los códigos asociados a estaciones de carga, descarga y señalización de

trayectorias, generando acciones de movimiento de acuerdo con la lógica programada. Los

resultados obtenidos durante las pruebas evidenciaron que el robot interpreta adecuadamente la

información visual y ejecuta las instrucciones correspondientes en tiempo real.

Figura 6

Reconocimiento de códigos QR.

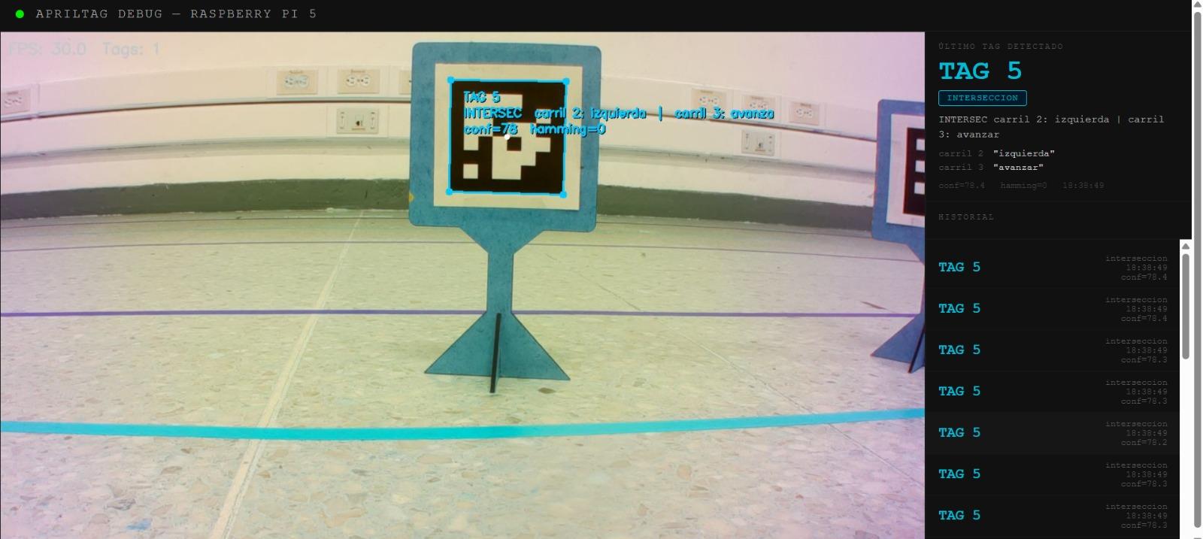
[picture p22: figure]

Nota. La imagen presenta la interfaz de procesamiento visual desarrollada en Python mediante

OpenCV, utilizada para detectar y decodificar códigos QR en tiempo real. El sistema permitió identificar señales de navegación y generar instrucciones de movimiento para el robot durante el

recorrido sobre la pista de validación. Elaboración propia (2026).

Durante las pruebas funcionales realizadas sobre la pista de validación, el robot ejecutó

correctamente los tres casos de prueba establecidos en el manual de usuario: seguimiento de

línea, reconocimiento de códigos QR y detección de carga en estación. El sistema mantuvo el

desplazamiento dentro del carril asignado durante el recorrido y logró reconocer los códigos QR,

asociados al inicio de carga, estación de descarga y señalización informativa de carriles,

respectivamente.

En el caso de prueba correspondiente al seguimiento de línea, el robot mantuvo

estabilidad en trayectorias rectas y curvas, evitando salir de los límites establecidos en la pista.

Este comportamiento evidenció un funcionamiento adecuado del sistema de locomoción, control

de motores y dirección Ackermann.

Figura 7

Seguimiento de línea.

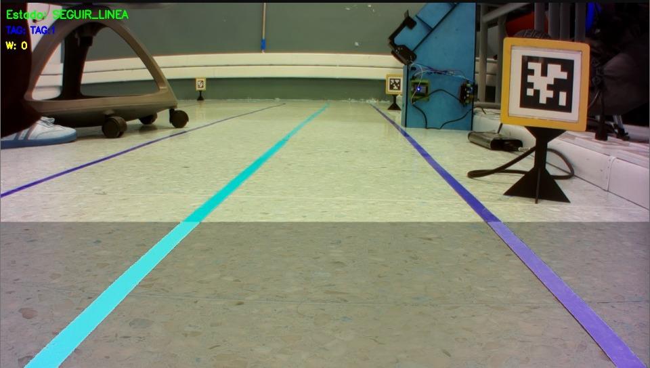
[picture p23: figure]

Nota. Durante las pruebas funcionales, el robot logró mantenerse dentro del carril asignado

mediante el procesamiento continuo de referencias visuales obtenidas por la cámara IMX219.

Este comportamiento permitió validar el funcionamiento del sistema de control y estabilidad

implementado en el prototipo. Elaboración propia (2026).

Por otra parte, durante el reconocimiento de códigos QR, el sistema logró identificar

correctamente las señales visuales ubicadas en la pista y responder mediante acciones

previamente programadas, como detención temporal y reanudación del recorrido. Esto permitió

validar el funcionamiento del sistema de visión artificial implementado sobre la Raspberry Pi 5.

Adicionalmente, el robot fue capaz de detenerse en la estación de carga y continuar el

recorrido después de confirmar la presencia de la carga transportada, demostrando coordinación

entre percepción visual, control de movimiento y lógica de navegación autónoma.

Figura 8

Robot en la estación de carga.

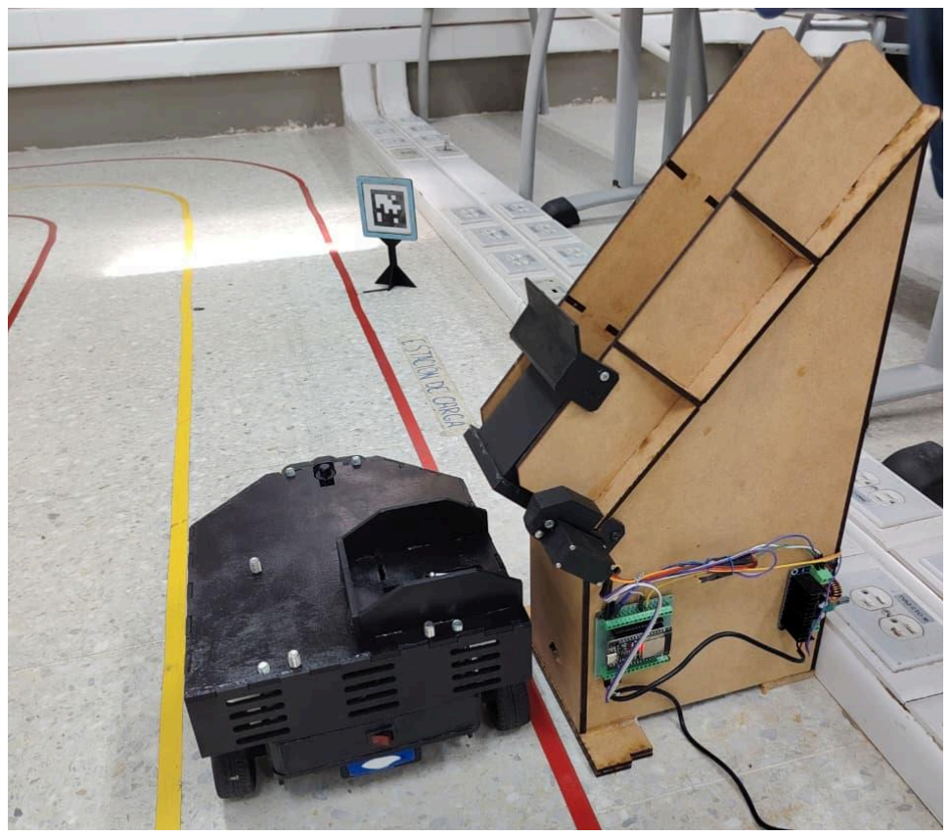
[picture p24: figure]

Nota. La figura muestra el momento en el que el robot realiza la detención automática frente a la

estación de carga como parte de la secuencia autónoma de navegación. Posteriormente, el

sistema verifica la presencia de la carga y reanuda el desplazamiento sobre la pista de pruebas.

Elaboración propia (2026).

Los resultados obtenidos permitieron verificar el cumplimiento de los objetivos

específicos planteados inicialmente, particularmente en aspectos relacionados con navegación

autónoma, integración electrónica, reconocimiento visual y estabilidad mecánica. De igual

manera, las pruebas realizadas demostraron que el sistema presenta un comportamiento funcional

y repetible dentro de entornos logísticos controlados.

Conclusiones

El desarrollo del robot autónomo ATLAS permitió integrar de manera progresiva

conocimientos de mecánica, electrónica, programación y visión artificial dentro de un único

sistema funcional orientado a procesos logísticos automatizados. A lo largo del proyecto, la

construcción del prototipo evidenció la importancia de la planificación metodológica y del

trabajo interdisciplinario para el desarrollo de soluciones robóticas aplicadas a entornos

controlados.

Inicialmente, el proyecto se enfocó en la definición de requerimientos técnicos y en el

diseño conceptual del sistema mecánico y electrónico. Posteriormente, mediante procesos de

modelado CAD, fabricación de componentes e integración de hardware, fue posible construir

una plataforma robótica estable y adaptable a las condiciones de la pista de pruebas. La

implementación del mecanismo de dirección tipo Ackermann contribuyó significativamente a

mejorar la maniobrabilidad del robot durante trayectorias curvas y desplazamientos continuos.

De manera simultánea, la integración entre Raspberry Pi 5 y ESP32 permitió establecer

una arquitectura distribuida de control capaz de separar las tareas de procesamiento visual y

control de movimiento. Esta organización favoreció la estabilidad operativa del sistema y facilitó

la comunicación en tiempo real entre los diferentes componentes del robot.

En el componente de software, el desarrollo de algoritmos de visión artificial mediante

Python y OpenCV permitió implementar procesos de reconocimiento de códigos QR y

navegación autónoma. Las pruebas funcionales demostraron que el sistema fue capaz de

interpretar correctamente la información visual presente en la pista y ejecutar acciones asociadas

al desplazamiento, detención y reanudación del recorrido.

Asimismo, las validaciones realizadas evidenciaron que el robot cumple adecuadamente

con los requerimientos planteados para la ejecución de recorridos autónomos dentro de la pista

de pruebas. El sistema mantuvo estabilidad durante el desplazamiento, respondió correctamente

ante los códigos QR detectados y logró completar las secuencias de navegación planteadas

durante los casos de prueba.

El desarrollo metodológico basado en Aprendizaje Basado en Proyectos permitió

estructurar el trabajo mediante etapas progresivas de diseño, integración, validación y mejora

continua. Esta metodología facilitó la corrección de errores durante el proceso de construcción y

fortaleció la articulación entre las diferentes áreas técnicas involucradas en el proyecto.

Finalmente, el proyecto ATLAS permitió evidenciar el potencial de los robots móviles

autónomos como herramientas aplicables a procesos de automatización logística y transporte

inteligente. Además de cumplir con los objetivos académicos y funcionales planteados

inicialmente, el desarrollo del prototipo establece una base tecnológica que puede ampliarse en futuras investigaciones relacionadas con navegación autónoma, evasión de obstáculos,

automatización industrial y robótica móvil aplicada a la Industria 4.0.

Referencias

Acta de constitución del proyecto robot autónomo ATLAS. (2025). Universidad

Tecnológica de Pereira, Facultad de Tecnología, Programa de Ingeniería Mecatrónica.

https://docs.google.com/document/d/1pEP2whKF3BkKWY76yrVcwxnDQFxJtWOt59tookOM

mHM/edit?usp=sharing (https://docs.google.com/document/d/1pEP2whKF3BkKWY76yrVcwxnDQFxJtWOt59tookOMmHM/edit?usp=sharing)

Arrichiello, F., Marino, A., & Pierri, F. (2017). Distributed fault-tolerant control for

networked robots in the presence of recoverable/unrecoverable faults and reactive behaviors.

Frontiers in Robotics and AI. https://doi.org/10.3389/frobt.2017.00002

Balachandran, A., et al. (2022). Autonomous navigation of an AMR using deep

reinforcement learning in warehouse environment. IEEE.

https://ieeexplore.ieee.org/document/9971804

Bogue, R. (2023). Mobile robots in smart warehouses: Developments and trends.

Industrial Robot. https://www.emerald.com/ir?utm

Bradski, G. (2000). The OpenCV library. Dr. Dobb’s Journal of Software Tools.

https://ptacts.uspto.gov/ptacts/public-informations/petitions/1558289/download-documents?artif

actId=8E9mKCVRLTzAIHYKaMMeW0Y7vRNLW2jO3IgIxCIvFTojVG2bGeGwSDI (https://ptacts.uspto.gov/ptacts/public-informations/petitions/1558289/download-documents)

Ellithy, K., et al. (2024). AGV and Industry 4.0 in warehouses: A comprehensive analysis

of existing literature and an innovative framework for flexible automation. The International

Journal of Advanced Manufacturing Technology. https://doi.org/10.1007/s00170-024-14127-0

El-Sayed, M. A., et al. (2024). AI-powered warehouse management: Autonomous mobile

robots and advanced optimization with NFC, MILP, and swarm algorithms. IEEE.

https://ieeexplore.ieee.org/document/11004979/

Keith, R., & La, H. (2024). Dynamic zoning of industrial environments with autonomous

mobile robots. arXiv. https://arxiv.org/abs/2411.07382

Khan, A., et al. (2021). Deep-learning-based real-time object detection for mobile robotic

applications. IEEE Access.

Kumar, R., et al. (2023). Mobile robotic manipulator based autonomous warehouse

operations. IEEE. https://ieeexplore.ieee.org/document/10374743

Manual de usuario: ATLAS robot autónomo — tres casos de prueba. (2025). Universidad

Tecnológica de Pereira, Facultad de Tecnología, Programa de Ingeniería Mecatrónica.

https://drive.google.com/file/d/1QRH3H6fQLt_Ddnmnmtwcvbl6MVRJJV2W/view?usp=sharin

g (https://drive.google.com/file/d/1QRH3H6fQLt_Ddnmnmtwcvbl6MVRJJV2W/view?usp=sharing)

Peyas, I. S., et al. (2022). Autonomous warehouse robot using deep Q-learning. arXiv.

https://arxiv.org/abs/2202.10019

Rosero, R., Zambrano, M., Minaya, C., & Salazar, M. (2025). Desarrollo de un robot

autónomo con visión artificial para evasión de obstáculos. Revista DATEH.

https://investigacion.utc.edu.ec/index.php/dateh/article/view/1191?utm

Siciliano, B., & Khatib, O. (2016). Springer handbook of robotics. Springer.

https://doi.org/10.1007/978-3-319-32552-1

Siegwart, R., Nourbakhsh, I. R., & Scaramuzza, D. (2019). Introduction to autonomous

mobile robots (2nd ed.). MIT Press.

https://mitpress.mit.edu/9780262015356/introduction-to-autonomous-mobile-robots/

Yarlagadda, V. K. (2024). Cutting-edge developments in robotics for smart warehousing

and logistics optimization. Robotics Xplore: USA Automation Digest.

https://roboticsxplore.com/index.php/rx/article/view/7?utm

Zhang, J., et al. (2023). Vision-based navigation for autonomous mobile robots: A review.

Robotics and Autonomous Systems.

https://www.sciencedirect.com/journal/robotics-and-autonomous-systems?utm

Anexos

Anexo A. Cronograma completo del proyecto

En el siguiente enlace puede consultarse el cronograma completo de planificación y seguimiento

de actividades desarrollado para el robot autónomo ATLAS:

CRONOGRAMA ATLAS (https://docs.google.com/spreadsheets/d/1hFkAv0x_6sTBsH9Db6LbuQTo_hz-SXHm/edit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)

Anexo B. Presupuesto completo del proyecto

En el siguiente enlace puede consultarse el presupuesto detallado de materiales, componentes y

recursos utilizados durante el desarrollo del robot autónomo ATLAS:

PRESUPUESTO ATLAS (https://docs.google.com/spreadsheets/d/1F3X6RJ5xXpCuQOEL4v0P_OzLx2RXQDj0/edit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)

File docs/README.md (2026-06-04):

# Documentación del Proyecto

Esta carpeta contiene la documentación asociada al desarrollo del proyecto G7ACKER, organizada bajo un enfoque de Aprendizaje Basado en Proyectos (ABP), permitiendo el seguimiento estructurado del proceso desde su planeación hasta su ejecución.

---

## Estructura

```id="0w6h9p"
docs/
│── acta_constitucion/
│   ├── Acta de Constitución.docx
│   ├── Propuesta formal.docx
│
│── bitacoras/
│   ├── FI-F-001 BITÁCORA SEMANA 4 y 5 - EJECUCIÓN.pdf
│   ├── FI-F-001 BITÁCORA SEMANA 6 y 7 - EJECUCIÓN.pdf
│   ├── FI-F-001 BITÁCORA SEMANA 8 y 9 - EJECUCIÓN.pdf
|   ├── FI-F-001 BITÁCORA SEMANA 10 y 11 - EJECUCIÓN.pdf
|   ├── FI-F-001 BITÁCORA SEMANA 12 y 13 - EJECUCIÓN.pdf
|   ├── FI-F-001 BITÁCORA SEMANA 14 y 15 - EJECUCIÓN.pdf
|   ├── FI-F-001 BITÁCORA SEMANA 16 y 17 - EJECUCIÓN.pdf
│
│── imagenes/
|
│── presentacion_final/
│   ├── ATLAS.pdf
│   ├── ARTICULO_POSTER_ATLAS.pdf
|
|── MATRIZ_CONTROL_DE_DOCUMENTOS.xlsx
│
│── README.md
```

---

## Contenido

### Acta de constitución

Contiene los documentos iniciales del proyecto:

* Acta de constitución
* Propuesta formal

Estos documentos definen el alcance, objetivos y lineamientos generales del desarrollo.

---

### Bitácoras

Registro semanal del desarrollo del proyecto, estructurado en:

* Ejecución: actividades previstas y actividades realizadas

Las bitácoras permiten llevar trazabilidad del progreso, identificar avances y documentar decisiones tomadas durante el desarrollo.

---

### Imágenes

Esta sección almacena:

* Fotografías del robot
* Evidencia del proceso de desarrollo
* Recursos visuales de apoyo

---

### Matriz de documentos

Archivo en formato Excel que centraliza el control de la documentación del proyecto.

Incluye:

* Registro de documentos generados
* Seguimiento de entregas
* Organización e inventario de la información

Esta matriz permite mantener un control estructurado de todos los archivos asociados al proyecto y asegurar la trazabilidad documental.

---

## Metodología

El proyecto se desarrolla bajo la metodología de **Aprendizaje Basado en Proyectos (ABP)**, lo que implica:

* Planificación iterativa
* Ejecución por fases
* Seguimiento continuo mediante bitácoras

---

## Propósito

Centralizar la documentación del proceso del proyecto para:

* Mantener trazabilidad del desarrollo
* Soportar la gestión del proyecto
* Facilitar la presentación y evaluación del trabajo

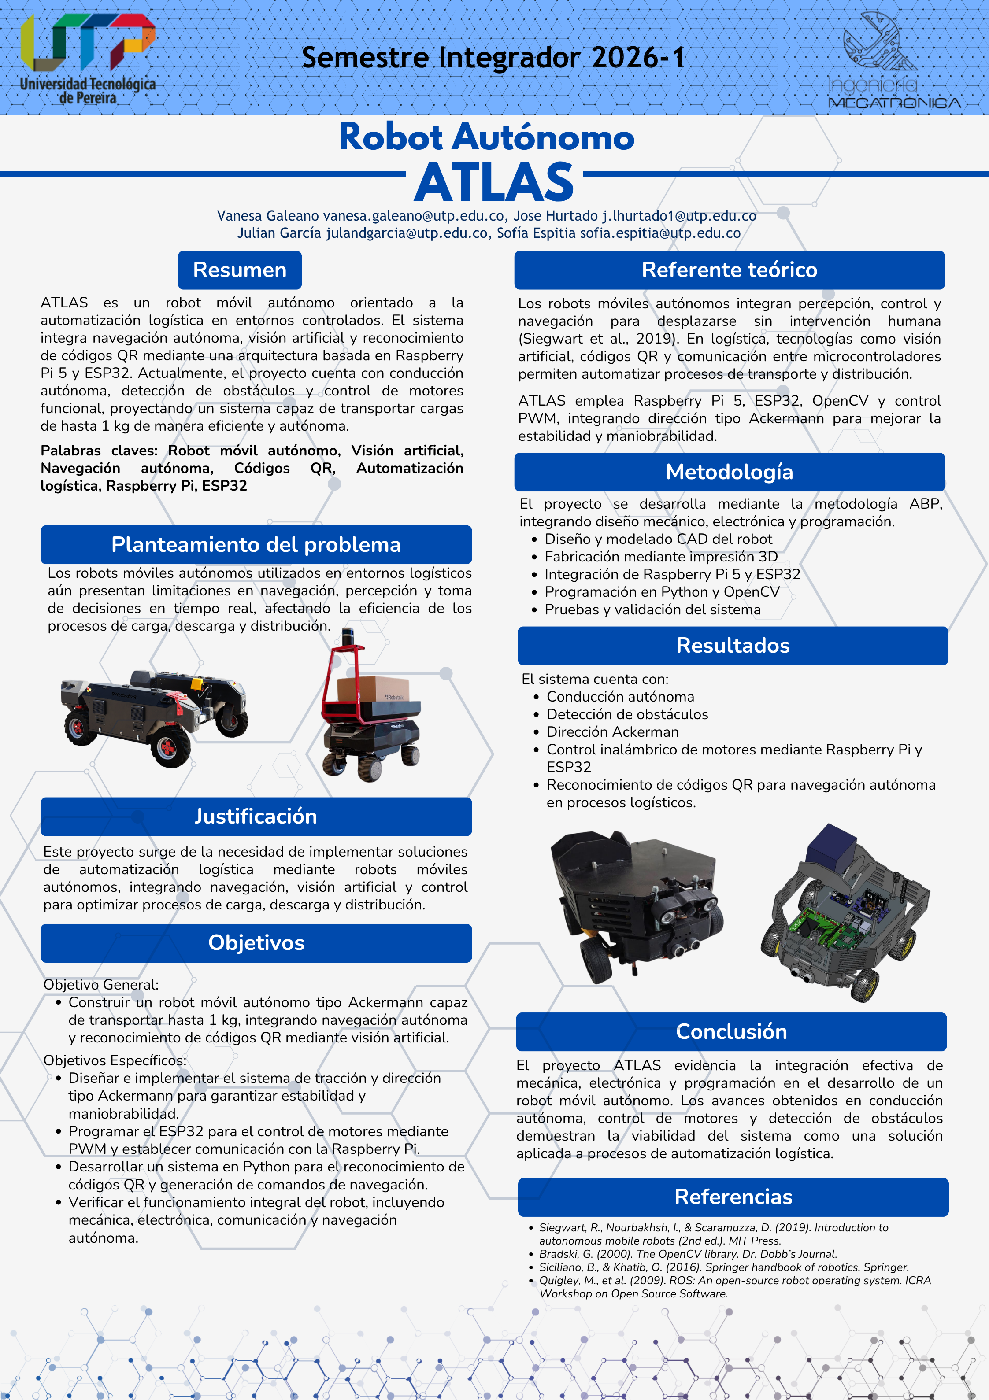
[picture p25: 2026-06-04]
docs/poster/ARTICULO_POSTER_ATLAS.png

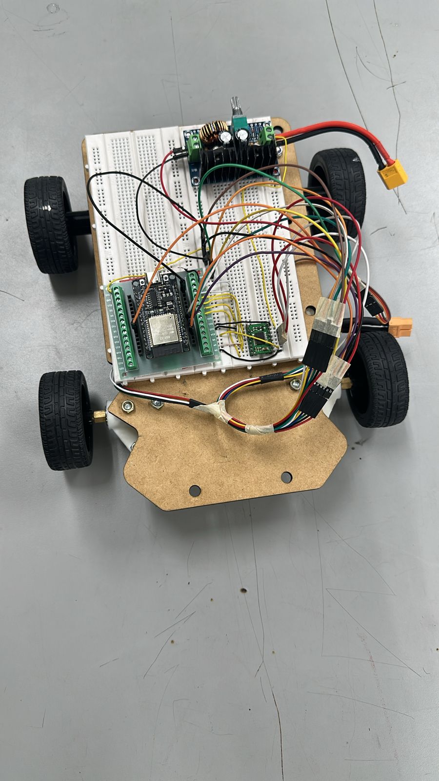
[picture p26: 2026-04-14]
docs/imagenes/ELECTRONICA_PROVICIONAL.jpeg

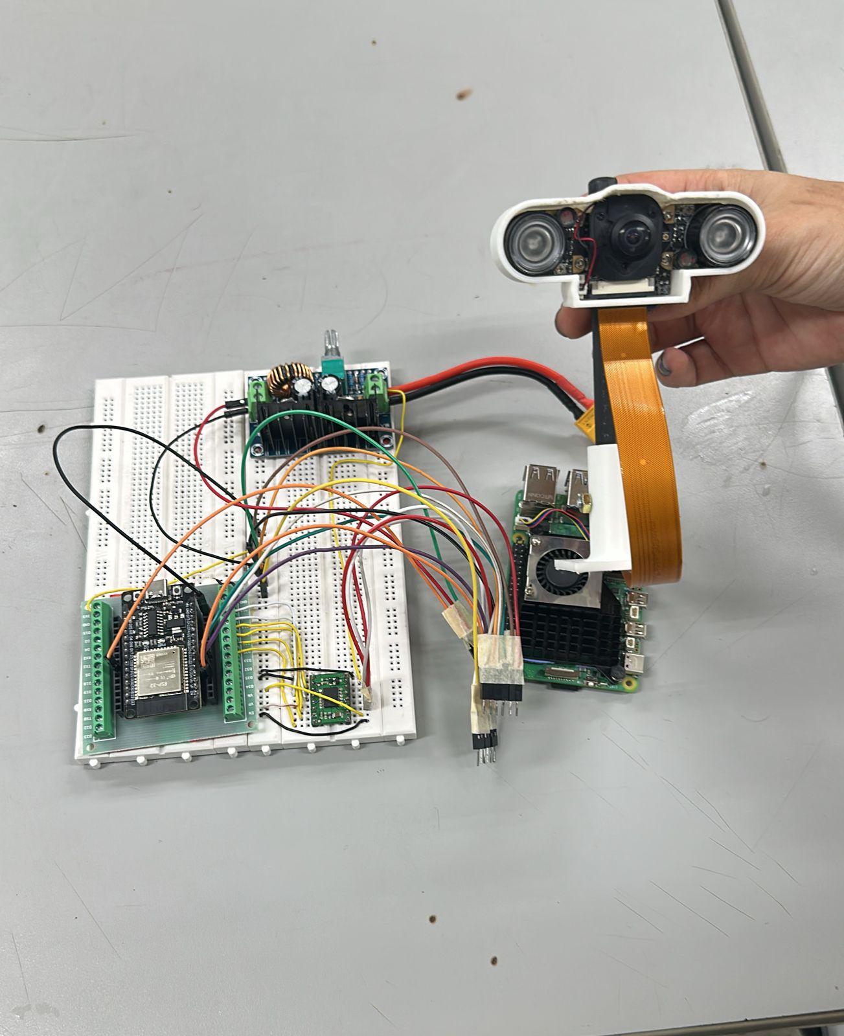
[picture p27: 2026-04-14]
docs/imagenes/CONEXIONES_ELECTRONICAS.jpeg

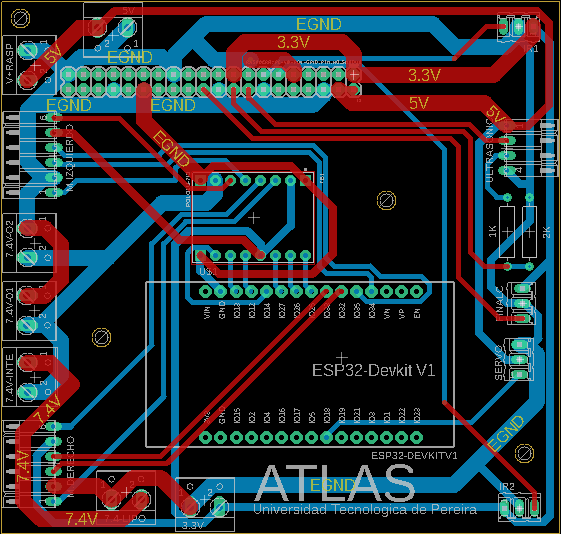
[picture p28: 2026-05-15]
hardware/pcb/PCB_RUTAS.png

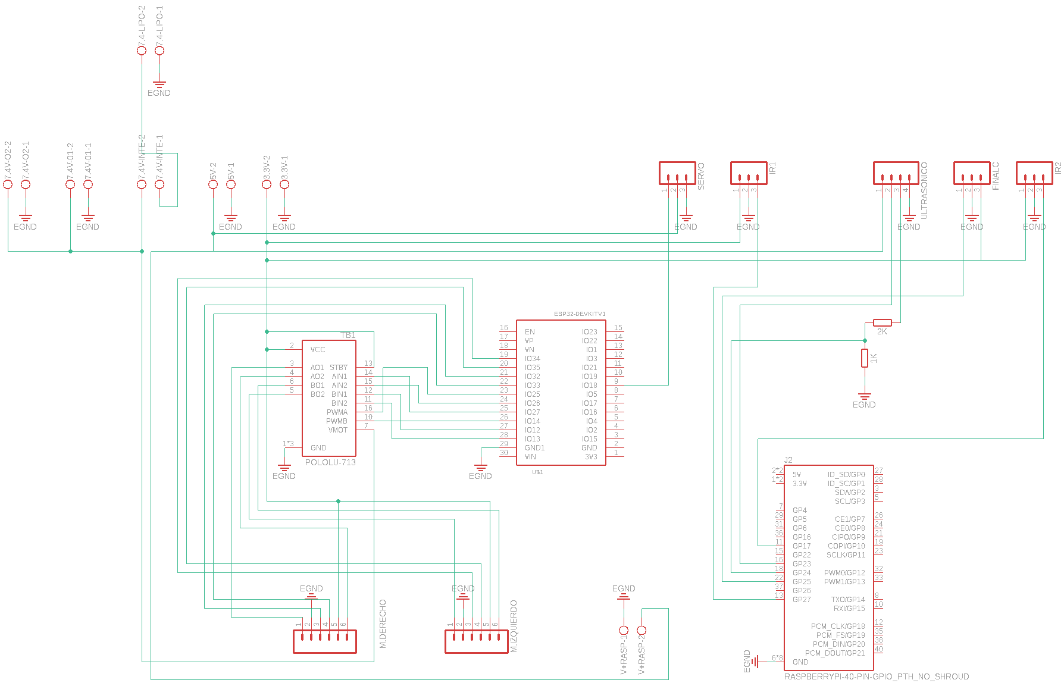
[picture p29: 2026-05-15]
hardware/esquematico/ESQUEMATICO_PCB.png

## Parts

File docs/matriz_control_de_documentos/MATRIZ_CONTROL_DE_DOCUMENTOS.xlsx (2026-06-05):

Robot Móvil Autónomo de Dirección Ackerman |  | LISTADO MAESTRO DE DOCUMENTOS
SGC-001
VERSION 01
2026-04-07
Número de Documento | Título del Documento | Versión | Fecha de Emisión/Revisión | Historial de Revisiones (Fecha – Autor – Descripción) | Estado | Autor | Revisor | Aprobador | Ubicación | Control de Acceso | Lista de Distribución | Período de Retención | Método de Eliminación | Referencias | Formato
DOC-001 | Acta de Constitución | 2.0 | 2026-02-27 | 13/02/2026 – Todos – Creación del documento (Versión 1.0, no aprobado por correcciones requeridas) | Aprobado | Julian Garcia | Vanesa Galeano | Tatiana Rengifo Oviedo | Repositorio GitHub (https://github.com/Espitiass/G7ACKER.git) | Lectura: Tatiana Rengifo Oviedo, Carlos Andres Rodriguez, Edward Gonzales Edward Andres Gonzalez Rios Escritura: Jose Diaz, Santiago Gutierrez, Ronaldo Ducuara | Equipo del proyecto | 3 Meses | Borrado seguro digital | Plan del Proyecto | PDF
 |  |  |  | 27/02/2026 – Todos – Documento aprobado (Versión 2.0)
DOC-002 | Propuesta Formal | 2.0 | 2026-03-13 | 03/03/2026 – Todos – Creación del documento (Versión 1.0, no aprobado por correcciones requeridas) | Aprobado | Jose Hurtado | Vanesa Galeano | Tatiana Rengifo Oviedo | Repositorio GitHub | Lectura: Tatiana Rengifo Oviedo, Carlos Andres Rodriguez, Edward Gonzales Edward Andres Gonzalez Rios Escritura: Jose Diaz, Santiago Gutierrez, Ronaldo Ducuara | Equipo del proyecto | 3 Meses | Borrado seguro digital | Plan del Desarrollo | PDF
 |  |  |  | 13/03/2026 – Todos – Documento aprobado (Versión 2.0)
DOC-003 | Bitacora 4 y 5 Planeación | 1.0 | 2026-02-20 | 13/03/2026 – Todos – Documento aprobado (Versión 1.0) | Aprobado | Vanesa Galeano | Sofía Espitia | Tatiana Rengifo Oviedo | Repositorio GitHub | Lectura: Tatiana Rengifo Oviedo, Carlos Andres Rodriguez, Edward Gonzales Edward Andres Gonzalez Rios Escritura: Jose Diaz, Santiago Gutierrez, Ronaldo Ducuara | Equipo del proyecto | 3 Meses | Borrado seguro digital | Planeación de actividades semana 4 y 5 | PDF
DOC-004 | Bitacora 4 y 5 Ejecución | 2.0 | 2026-03-05 | 05/03/2026 – Todos – Creación del documento (Versión 1.0, no aprobado por correcciones requeridas) | En proceso de aprovación | Sofía Espitia | Vanesa Galeano | Tatiana Rengifo Oviedo | Repositorio GitHub | Lectura: Tatiana Rengifo Oviedo, Carlos Andres Rodriguez, Edward Gonzales Edward Andres Gonzalez Rios Escritura: Jose Diaz, Santiago Gutierrez, Ronaldo Ducuara | Equipo del proyecto | 3 Meses | Borrado seguro digital | Registro de planeación semana 4 y 5 | PDF
 |  |  |  | 07/04/2026 – Todos – Documento en proceso de aprobación (Versión 2.0)
DOC-005 | Bitacora 6 y 7 Planeación | 1.0 | 2026-03-05 | 03/04/2026 – Todos – Documento aprobado (Versión 1.0) | Aprobado | Sofía Espitia | Vanesa Galeano | Tatiana Rengifo Oviedo | Repositorio GitHub | Lectura: Tatiana Rengifo Oviedo, Carlos Andres Rodriguez, Edward Gonzales Edward Andres Gonzalez Rios Escritura: Jose Diaz, Santiago Gutierrez, Ronaldo Ducuara | Equipo del proyecto | 3 Meses | Borrado seguro digital | Planeación de actividades semana 6 y 7 | PDF
DOC-006 | Bitacora 6 y 7 Ejecución | 2.0 | 2026-03-20 | 20/03/2026 – Todos – Creación del documento (Versión 1.0, no aprobado por correcciones requeridas) | En proceso de aprovación | Jose Hurtado | Sofía Espitia | Tatiana Rengifo Oviedo | Repositorio GitHub | Lectura: Tatiana Rengifo Oviedo, Carlos Andres Rodriguez, Edward Gonzales Edward Andres Gonzalez Rios Escritura: Jose Diaz, Santiago Gutierrez, Ronaldo Ducuara | Equipo del proyecto | 3 Meses | Borrado seguro digital | Registro de planeación semana 6 y 7 | PDF
 |  |  |  | 10/04/2026 – Todos – Documento en proceso de aprobación (Versión 2.0)
DOC-007 | Bitacora 8 y 9 Planeación | 1.0 | 2026-03-20 | 20/03/2026 – Todos – Documento aprobado (Versión 1.0) | Aprobado | Jose Hurtado | Sofía Espitia | Tatiana Rengifo Oviedo | Repositorio GitHub | Lectura: Tatiana Rengifo Oviedo, Carlos Andres Rodriguez, Edward Gonzales Edward Andres Gonzalez Rios Escritura: Jose Diaz, Santiago Gutierrez, Ronaldo Ducuara | Equipo del proyecto | 3 Meses | Borrado seguro digital | Planeación de actividades semana 8 y 9 | PDF
DOC-008 | Bitacora 8 y 9 Ejecución | 1.0 | 2026-04-03 | 03/04/2026 – Todos – Documento aprobado (Versión 1.0) | Aprobado | Julian Garcia | Vanesa Galeano | Tatiana Rengifo Oviedo | Repositorio GitHub | Lectura: Tatiana Rengifo Oviedo, Carlos Andres Rodriguez, Edward Gonzales Edward Andres Gonzalez Rios Escritura: Jose Diaz, Santiago Gutierrez, Ronaldo Ducuara | Equipo del proyecto | 3 Meses | Borrado seguro digital | Registro de planeación semana 8 y 9 | PDF
DOC-009 | Bitacora 10 y 11 Planeación | 1.0 | 2026-04-03 | 03/04/2026 – Todos – Documento aprobado (Versión 1.0) | Aprobado | Julian Garcia | Vanesa Galeano | Tatiana Rengifo Oviedo | Repositorio GitHub | Lectura: Tatiana Rengifo Oviedo, Carlos Andres Rodriguez, Edward Gonzales Edward Andres Gonzalez Rios Escritura: Jose Diaz, Santiago Gutierrez, Ronaldo Ducuara | Equipo del proyecto | 3 Meses | Borrado seguro digital | Planeación de actividades semana 10 y 11 | PDF
DOC-010 | Bitacora 10 y 11 Ejecución | 1.0 | 2026-04-17 | 17/04/2026 – Todos – Documento aprobado (Versión 1.0) | Aprobado | Julian Garcia | Sofía Espitia | Tatiana Rengifo Oviedo | Repositorio GitHub | Lectura: Tatiana Rengifo Oviedo, Carlos Andres Rodriguez, Edward Gonzales Edward Andres Gonzalez Rios Escritura: Jose Diaz, Santiago Gutierrez, Ronaldo Ducuara | Equipo del proyecto | 3 Meses | Borrado seguro digital | Registro de planeación semana 10 y 11 | PDF
DOC-011 | Bitacora 12 y 13 Planeación | 1.0 | 2026-04-17 | 17/04/2026 – Todos – Documento aprobado (Versión 1.0) | Aprobado | Sofía Espitia | Vanesa Galeano | Tatiana Rengifo Oviedo | Repositorio GitHub | Lectura: Tatiana Rengifo Oviedo, Carlos Andres Rodriguez, Edward Gonzales Edward Andres Gonzalez Rios Escritura: Jose Diaz, Santiago Gutierrez, Ronaldo Ducuara | Equipo del proyecto | 3 Meses | Borrado seguro digital | Planeación de actividades semana 12 y 13 | PDF
DOC-012 | Bitacora 12 y 13 Ejecución | 1.0 | 2026-05-01 | 01/05/2026 – Todos – Documento aprobado (Versión 1.0) | Aprobado | Sofía Espitia | Vanesa Galeano | Tatiana Rengifo Oviedo | Repositorio GitHub | Lectura: Tatiana Rengifo Oviedo, Carlos Andres Rodriguez, Edward Gonzales Edward Andres Gonzalez Rios Escritura: Jose Diaz, Santiago Gutierrez, Ronaldo Ducuara | Equipo del proyecto | 3 Meses | Borrado seguro digital | Planeación de actividades semana 12 y 13 | PDF
DOC-013 | Bitacora 14 y 15 Planeación | 1.0 | 2026-05-01 | 01/05/2026 – Todos – Documento aprobado (Versión 1.0) | Aprobado | Vanesa Galeano | Sofía Espitia | Tatiana Rengifo Oviedo | Repositorio GitHub | Lectura: Tatiana Rengifo Oviedo, Carlos Andres Rodriguez, Edward Gonzales Edward Andres Gonzalez Rios Escritura: Jose Diaz, Santiago Gutierrez, Ronaldo Ducuara | Equipo del proyecto | 3 Meses | Borrado seguro digital | Planeación de actividades semana 14 y 15 | PDF
DOC-014 | Bitacora 14 y 15 Ejecución | 1.0 | 2026-05-15 | 15/05/2026 – Todos – Documento aprobado (Versión 1.0) | Aprobado | Jose Hurtado | Sofía Espitia | Tatiana Rengifo Oviedo | Repositorio GitHub | Lectura: Tatiana Rengifo Oviedo, Carlos Andres Rodriguez, Edward Gonzales Edward Andres Gonzalez Rios Escritura: Jose Diaz, Santiago Gutierrez, Ronaldo Ducuara | Equipo del proyecto | 3 Meses | Borrado seguro digital | Ejecución de actividades semana 14 y 15 | PDF
DOC-015 | Bitacora 16 y 17 Planeación | 1.0 | 2026-05-15 | 15/05/2026 – Todos – Documento aprobado (Versión 1.0) | Aprobado | Julián García | Sofía Espitia | Tatiana Rengifo Oviedo | Repositorio GitHub | Lectura: Tatiana Rengifo Oviedo, Carlos Andres Rodriguez, Edward Gonzales Edward Andres Gonzalez Rios Escritura: Jose Diaz, Santiago Gutierrez, Ronaldo Ducuara | Equipo del proyecto | 3 Meses | Borrado seguro digital | Planeación de actividades semana 16 y 17 | PDF
DOC-016 | Bitacora 16 y 17 Ejecución | 1.0 | 2026-05-29 | 29/05/2026 – Todos – Documento aprobado (Versión 1.0) | Aprobado | Sofía Espitia | Vanesa Galeano | Tatiana Rengifo Oviedo | Repositorio GitHub | Lectura: Tatiana Rengifo Oviedo, Carlos Andres Rodriguez, Edward Gonzales Edward Andres Gonzalez Rios Escritura: Jose Diaz, Santiago Gutierrez, Ronaldo Ducuara | Equipo del proyecto | 3 Meses | Borrado seguro digital | Ejecución de actividades semana 16 y 18 | PDF
DOC-017 | Presentación final | 1.1 | 2026-05-20 | 20/05/2026 – Todos – Documento aprobado (Versión 1.0) | Aprobado | Jose Hurtado | Vanesa Galeano | Tatiana Rengifo Oviedo | Repositorio GitHub | Lectura: Tatiana Rengifo Oviedo, Carlos Andres Rodriguez, Edward Gonzales Edward Andres Gonzalez Rios Escritura: Jose Diaz, Santiago Gutierrez, Ronaldo Ducuara | Equipo del proyecto | 3 Meses | Borrado seguro digital | Presentación final | PDF
DOC-018 | Poster | 1.0 | 2026-05-20 | 20/05/2026 – Todos – Documento aprobado (Versión 1.0) | Aprobado | Sofía Espitia | Vanesa Galeano | Tatiana Rengifo Oviedo | Repositorio GitHub | Lectura: Tatiana Rengifo Oviedo, Carlos Andres Rodriguez, Edward Gonzales Edward Andres Gonzalez Rios Escritura: Jose Diaz, Santiago Gutierrez, Ronaldo Ducuara | Equipo del proyecto | 3 Meses | Borrado seguro digital | Poster | PDF

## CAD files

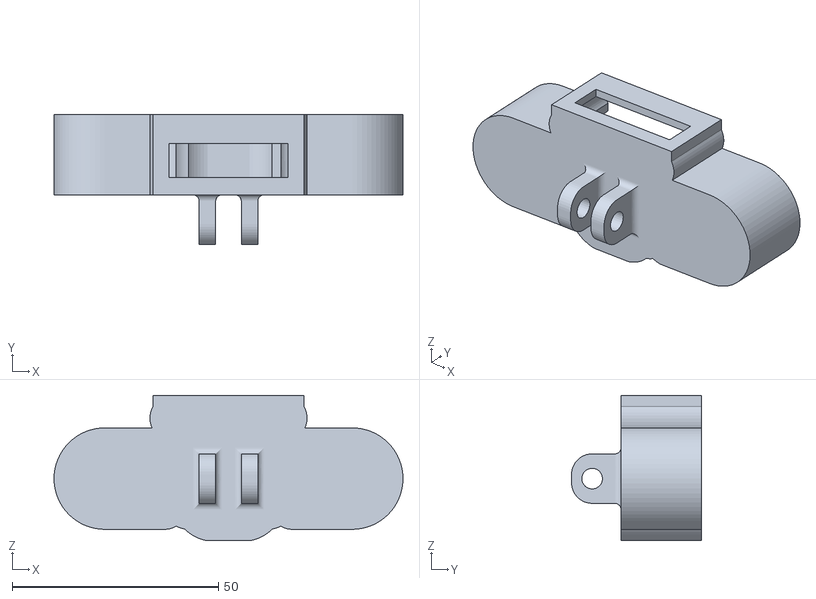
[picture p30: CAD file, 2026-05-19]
mechanical/Diseños_finales/Soporte_camara/Ensamble camara 2.stl
84.6 x 31.5 x 35.3

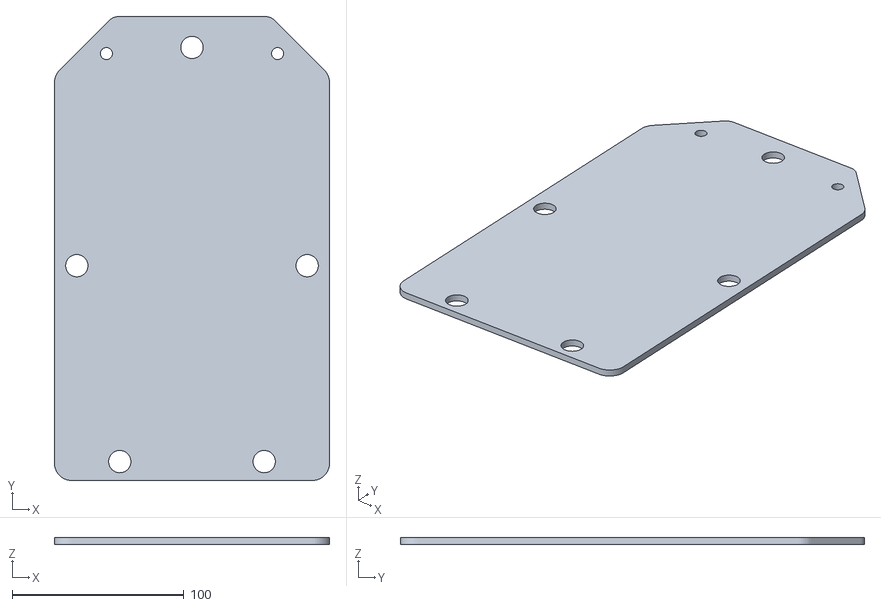
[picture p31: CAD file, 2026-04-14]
mechanical/Diseños_de_prueba/bases/base_piso_3_carga.stl
160.1 x 270.0 x 4.00

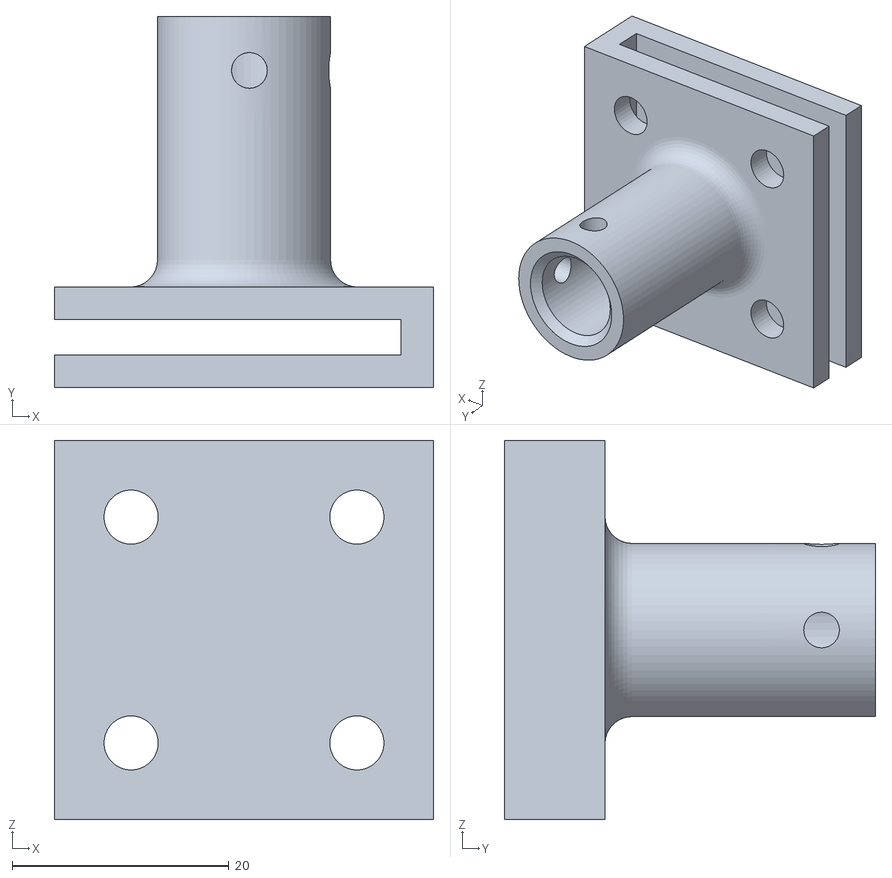
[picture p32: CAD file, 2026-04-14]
mechanical/Diseños_de_prueba/Camara/base_camara.stl
35.0 x 34.3 x 35.0

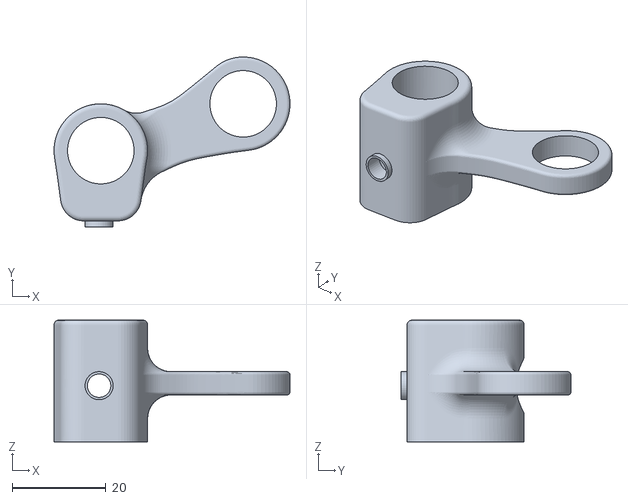
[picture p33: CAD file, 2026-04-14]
mechanical/Diseños_de_prueba/direccion_v2/PILAR_DER.stl
50.4 x 36.3 x 26.0

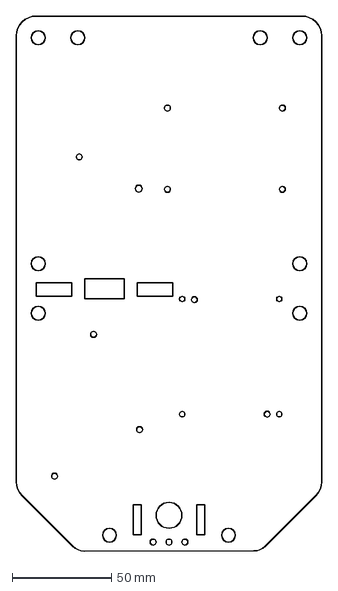
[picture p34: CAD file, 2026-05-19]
mechanical/Diseños_finales/Bases/Base_Piso_2_electronica.dxf
154.0 x 270.0 mm

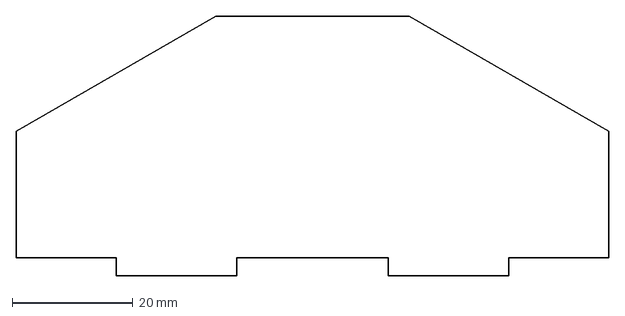
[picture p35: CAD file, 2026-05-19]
mechanical/Diseños_finales/Bases/Paredes_robot/Lateral trasero carga.dxf
98.0 x 43.0 mm

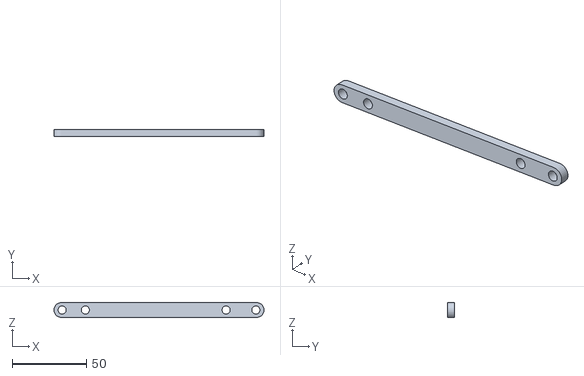
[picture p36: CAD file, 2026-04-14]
mechanical/Diseños_finales/direccion_v3/barra_soportes_giratorios_v3.stl
141.4 x 5.00 x 10.0

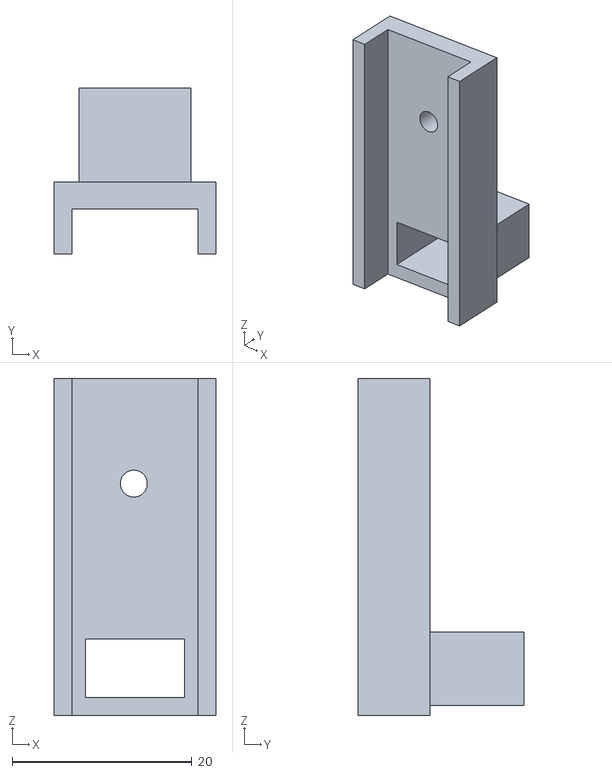
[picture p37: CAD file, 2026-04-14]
mechanical/Diseños_finales/soporte_infrarrojo/soporte_infrarrojo.stl
18.0 x 18.5 x 37.5

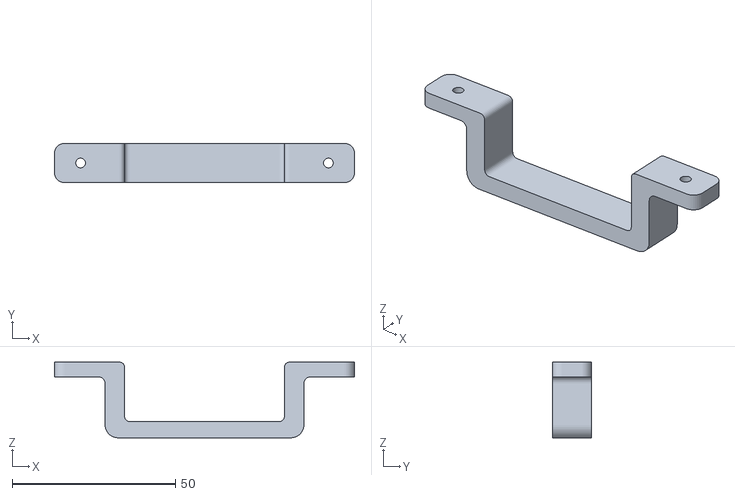
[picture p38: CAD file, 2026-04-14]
mechanical/Diseños_finales/soporte_lipo_v1/soporte_bateria_v1.stl
92.0 x 12.0 x 23.2

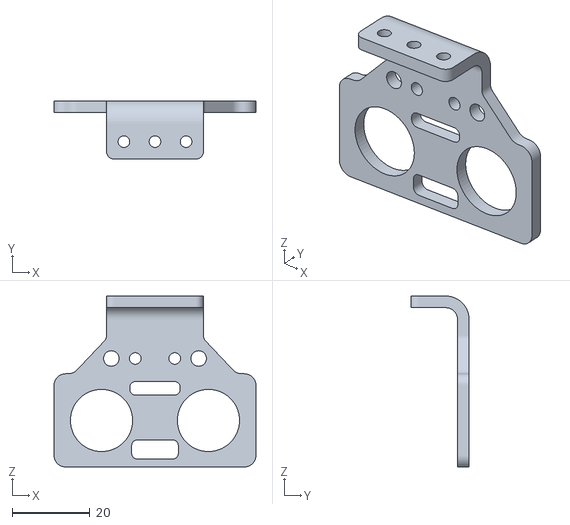
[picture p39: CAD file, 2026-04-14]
mechanical/Diseños_finales/soporte_ultrasonico/soporte_ultrasonico.stl
52.0 x 15.0 x 44.0

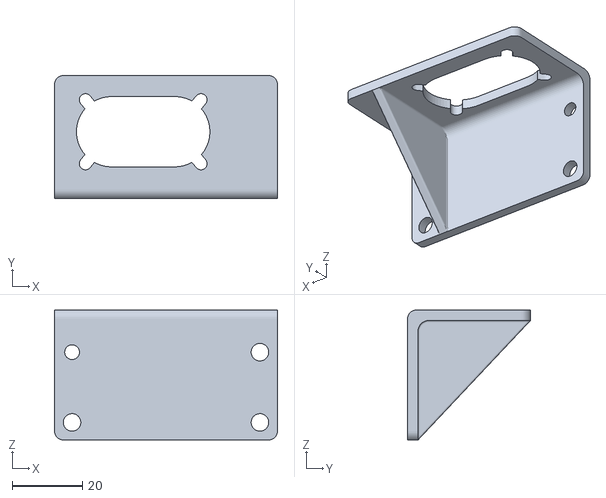
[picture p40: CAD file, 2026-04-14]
mechanical/Diseños_finales/Tracción/soporte_motor_izquierdo.stl
63.5 x 35.0 x 37.0

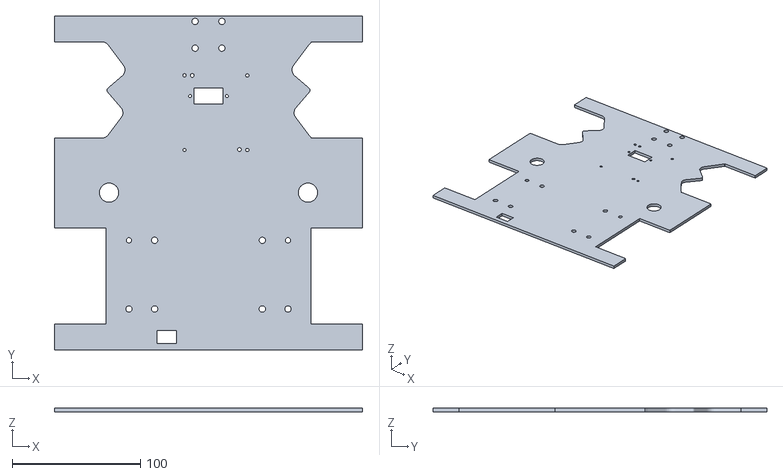
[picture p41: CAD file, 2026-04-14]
mechanical/Diseños_de_prueba/bases/base_v1.stl
240.0 x 260.0 x 3.00

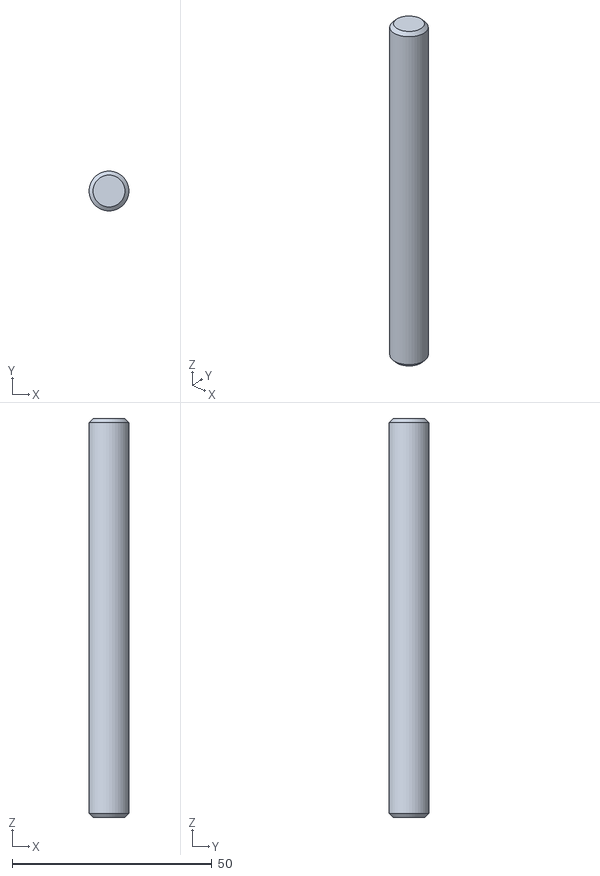
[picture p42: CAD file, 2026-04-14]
mechanical/Diseños_de_prueba/Camara/pilar_camara.stl
10.0 x 10.0 x 100.0

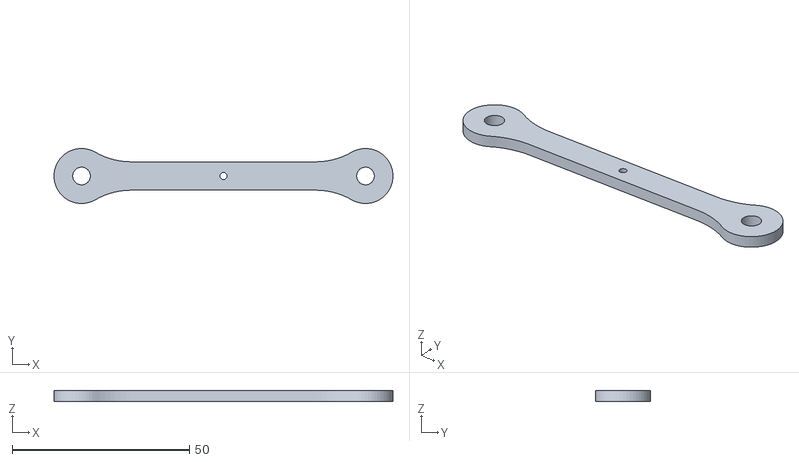
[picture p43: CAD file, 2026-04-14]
mechanical/Diseños_de_prueba/direccion_v2/BARRA_DIRECCION_V2.stl
95.5 x 15.5 x 3.00

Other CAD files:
mechanical/Diseños_finales/Bases/Base_Piso_1_mot_ack.dxf
mechanical/Diseños_finales/Bases/Paredes_robot/Soporte en impresión final.stl
mechanical/Diseños_finales/direccion_v3/barra+direccion_v3.stl
mechanical/Diseños_finales/Soporte_camara/base camara.stl
hardware/pcb/PCB.f3z
mechanical/Diseños_de_prueba/Camara/base_camara.f3d
mechanical/Diseños_de_prueba/Camara/pilar_camara.f3d
mechanical/Diseños_de_prueba/bases/base_piso_3_carga.f3d
mechanical/Diseños_de_prueba/bases/base_v1.f3d
mechanical/Diseños_de_prueba/direccion_v1/ACOPLE_RUEDA_BARRA_DER.f3d
mechanical/Diseños_de_prueba/direccion_v1/ACOPLE_RUEDA_BARRA_DER.stl
mechanical/Diseños_de_prueba/direccion_v1/ACOPLE_RUEDA_BARRA_IZQ.f3d
mechanical/Diseños_de_prueba/direccion_v1/ACOPLE_RUEDA_BARRA_IZQ.stl
mechanical/Diseños_de_prueba/direccion_v1/ACOPLE_SERVO.f3d
mechanical/Diseños_de_prueba/direccion_v1/ACOPLE_SERVO.stl
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

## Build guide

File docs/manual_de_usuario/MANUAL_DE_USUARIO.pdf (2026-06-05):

# ROBOT AUTÓNOMO

# ATLAS

# MANUAL DEL USUARIO

## PROGRAMA INGENIERÍA MECATRÓNICA

## UNIVERSIDAD TECNOLÓGICA DE PEREIRA

## PREFACIO

Este manual describe el funcionamiento, la operación y los cuidados requeridos para el uso seguro del robot autónomo ATLAS. El seguimiento de las instrucciones aquí presentadas contribuye a un funcionamiento confiable, prolonga la vida útil del sistema y reduce el riesgo de fallas durante la operación. Se recomienda leer completamente este documento antes de poner el robot en funcionamiento.

# TABLA DE

CONTENIDO.

8.3.1 Procedimiento para desmontar ruedas delanteras

8.3.2 Procedimiento para desmontar ruedas traseras..11

# 1. Información al usuario

### 1.1 Introducción

Este manual de usuario describe el funcionamiento y la operación del robot autónomo desarrollado para desplazarse de manera segura y eficiente dentro de una pista de pruebas. El sistema integra capacidades de navegación, percepción del entorno y manipulación básica de objetos, permitiendo ejecutar tareas de forma automática.

El robot utiliza un sistema de dirección Ackerman, que proporciona un comportamiento de conducción estable y similar al de un vehículo real. Está equipado con una cámara IMX219, encargada de capturar información visual para el seguimiento de carriles. Toda la información es procesada por una Raspberry Pi 5, que actúa como unidad central de control. La tracción del robot está compuesta por motores JGY‑370 con encoders, los cuales permiten un control preciso de velocidad y posición, garantizando maniobras exactas y desplazamientos estables.
Entre sus funciones principales se encuentran:
- Navegación autónoma dentro de la pista de pruebas.
- Detección de obstáculos y detención automática.
- Seguimiento de carriles mediante visión artificial.
- Capacidad para recoger, transportar y descargar una carga de hasta 1 kg en estaciones designadas dentro del recorrido.
- Control de movimiento preciso gracias a los encoders.
Este documento proporciona las instrucciones necesarias para la correcta operación, configuración y mantenimiento del robot, asegurando un uso adecuado y prolongando su vida útil.

# 2. Ubicación de componentes

### 2.1 Descripción general de los componentes

El robot ATLAS incluye los siguientes componentes principales
- Chasis del robot
- Ruedas
- Cámara IMX219
- Raspberry pi 5
- Reguladores de voltaje

- Bateria turnigy 5000 mAh

### 2.2 Diagrama del Robot Atlas

Fig. 1. Vista superior

1. Llantas de goma 65 mm
2. Raspberry pi 5
3. Camara IMX 219
4. PCB
5. Regulador de voltaje LM2596
6. Regulador de voltaje XL4016

Fig. 2. Vista Inferior

7. Motores JGY 370 6 V 100 RPM con encoder.
8. Batería lipo turnigy 5000 mAh 7,4 V.
9. Soportes para motores JGY 370 en PLA.
10. Servomotor MG90S
11. Componentes sistema Ackermann.

Fig. 3. Vista superior base de carga

12. Final de carrera
13. Carga con medidas 80x65x65 mm
14. Paredes laterales carga
15. Base superior de carga

# 3. Inspección antes de operar el robot

Antes de encender el robot es necesario realizar los siguientes pasos.
1. Retire la tapa lateral izquierda inferior.

Fig. 4. Tapa lateral izquierda inferior

2. Identifique el conector salva lipo de la batería Turnigy como se aprecia en la Fig. 5.

Fig. 5. Conector salva Lipo

3. Realice la conexión del conector en la alarma lipo y verifique el voltaje de la batería, si el voltaje de la batería es inferior a 6,6 V es necesario poner a cargar la batería, el voltaje máximo de la batería cargada es 8,4 V.
Nota: Si la alarma LiPo se activa, detenga y apague el robot de inmediato. Luego, verifique el voltaje de la batería y recárguela antes de continuar con la operación.

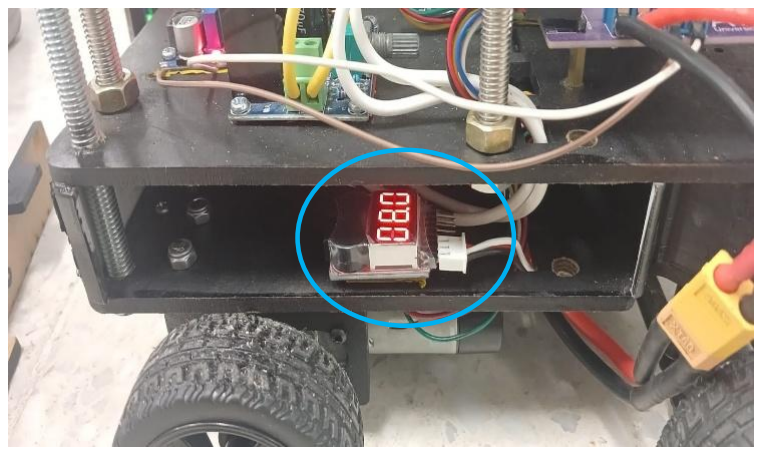
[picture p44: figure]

Fig. 6. Verificación con alama Lipo

# 4.Funcionamiento del robot

Siga los pasos indicados a continuación en el orden establecido para inicializar correctamente el sistema. Además, realice un reconocimiento de la pista de prueba, tal como se muestra en la Fig. 7.

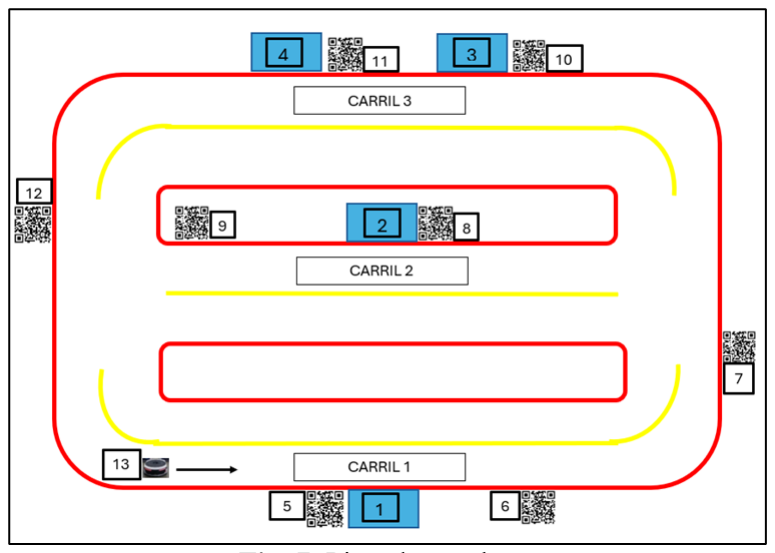
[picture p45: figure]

Fig. 7. Pista de prueba

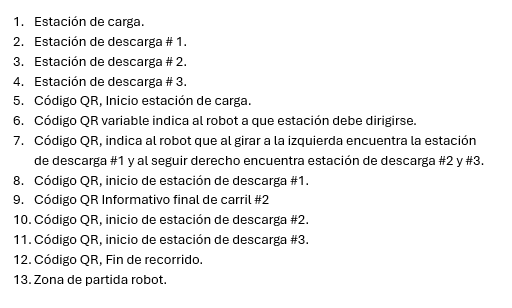
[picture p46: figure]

Fig. 8. Componentes pista de prueba

### 4.1 Posicionamiento en la pista

Ubique el robot en la zona de partida marcada en la pista, tal como se indica en la Fig. 9.

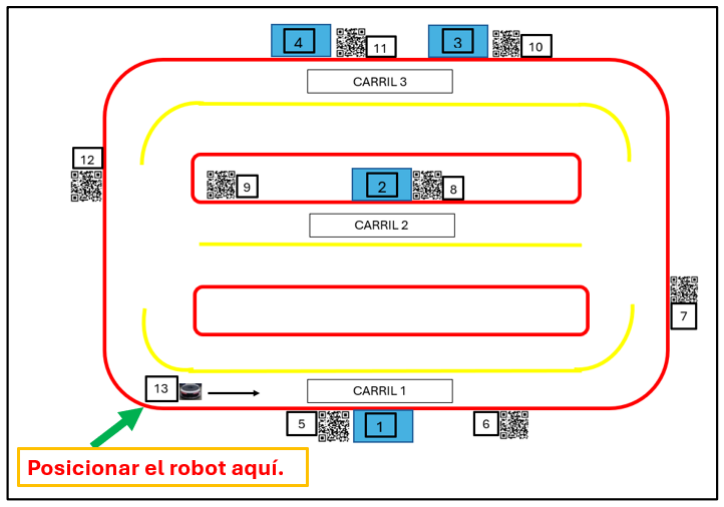
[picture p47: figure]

Fig. 9. Posicionamiento del robot en pista

### 4.2 Encendido del robot

1. Localice el interruptor de encendido en la parte trasera del robot.

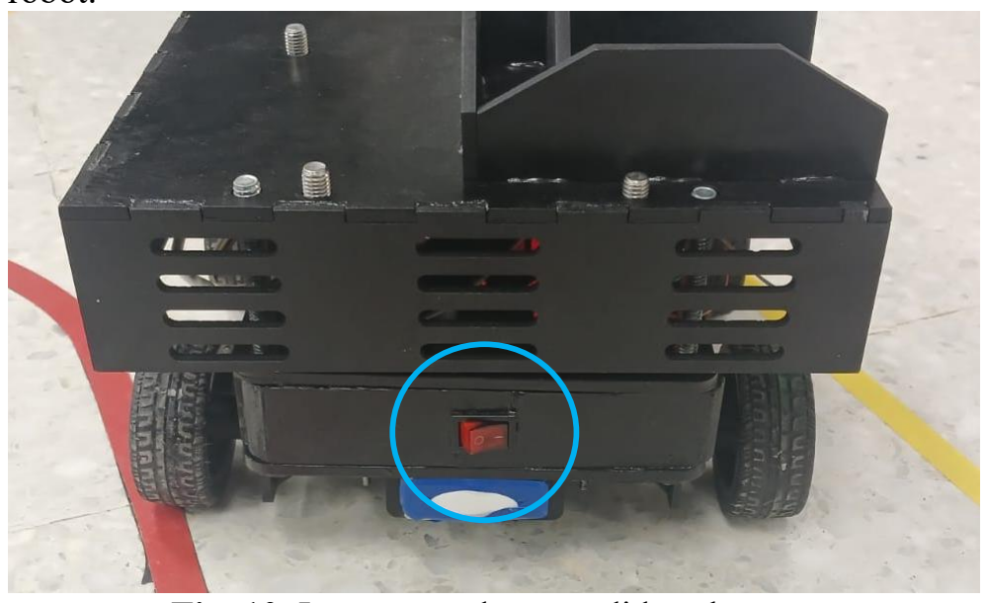
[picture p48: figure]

Fig. 10. Interruptor de encendido robot

2. Active el interruptor para encender el sistema.

### 4.3 Conexión SSH desde Visual Studio Code

1. Conectarse a la red WIFI (Integrador_5G) con clave de acceso (Mecatronica2026)
2. Abrir el programa visual Studio Code, vaya a extensiones con (Ctrl+Shift+X), busque e instale "Remote – SSH"

### 3. Presione F1 ó Ctrl+Shift+P, y seleccione Remote-SSH:

Connect to Host, tal cual aparece en la Fig. 11.

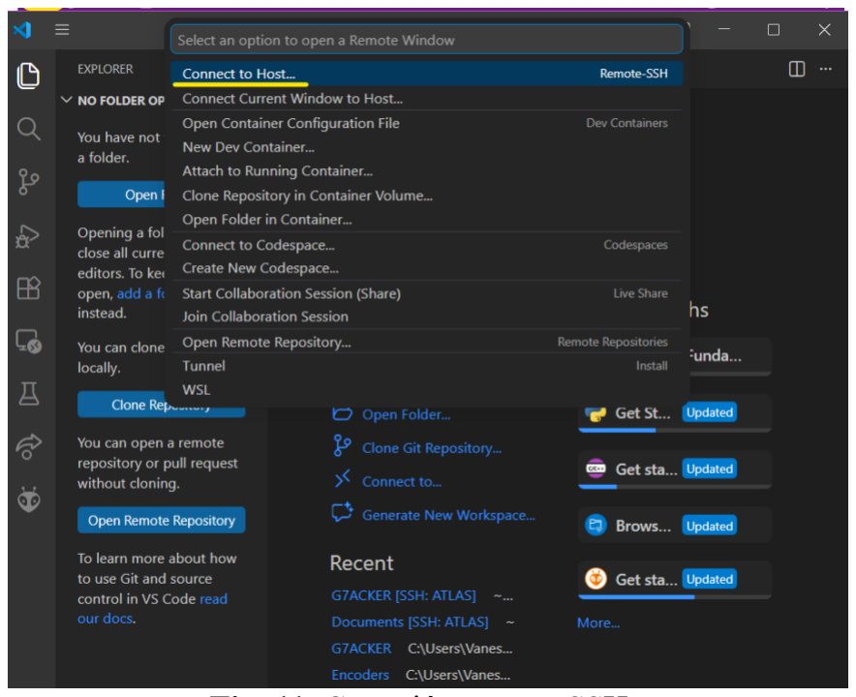
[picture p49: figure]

Fig. 11. Conexión remota SSH

4. Escribir en el terminal ssh grupo7@192.168.0.102 y presione Enter.
5. Si se lo pide, seleccione la plataforma (Linux) y acepte la huella digital.
6. Introduzca la contraseña de la Raspberry Pi cuando se solicite la contraseña es (grupo7)

4.4 Apertura del proyecto.

Una vez conectado por SSH, abra la carpeta del proyecto:
7. Haga clic en "Open Folder".
8. Navegue hasta la carpeta: DOCUMENTS → G7ACKER
9. Haga clic en OK para confirmar.

Fig.12 Carpeta del proyecto G7ACKER

### 4.5 Ejecución del Código Principal

10. En el explorador de archivos de VS Code, seleccione el archivo main.py
11. Haga clic en RUN para ejecutar el programa.

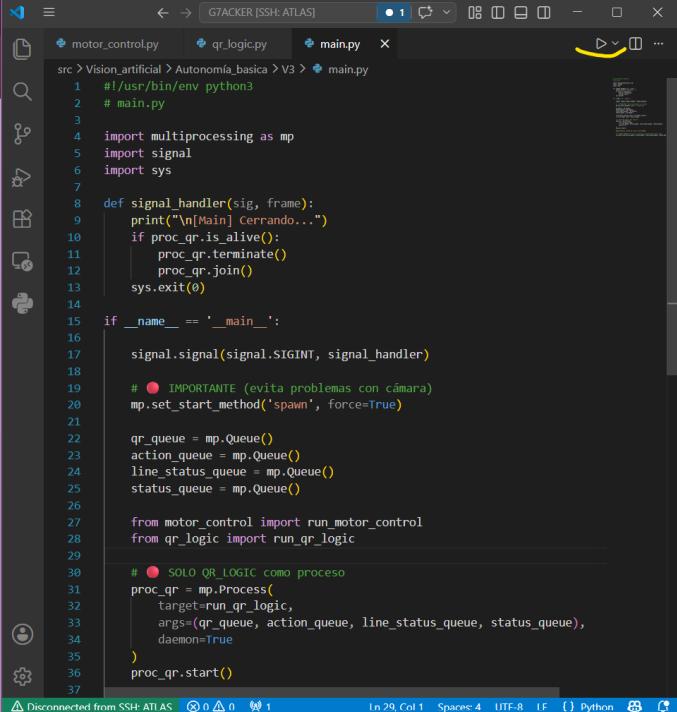
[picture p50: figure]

Fig. 13. Ejecución del código main

### 4.6 Acceso a la Cámara del Robot

Al ejecutar el programa, la terminal muestra la dirección IP de la cámara en tiempo real.
Siga estos pasos:
12. En la terminal, localice la dirección IP mostrada.
13. Mantenga presionada la tecla Ctrl y haga clic izquierdo sobre la dirección IP para abrirla en el navegador.
Dirección IP fija: http://192.168.0.102:5000/
Nota: La dirección IP es fija y se renueva automáticamente cada vez que el código se ejecuta nuevamente.

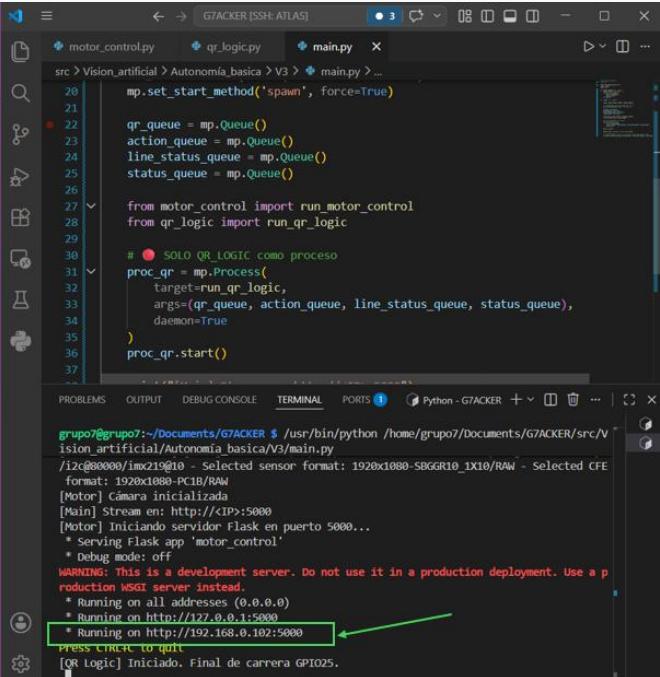
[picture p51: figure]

Fig. 14. Dirección IP para acceso a la cámara

# 5.Verificación de 3 casos de prueba

Table 1. Casos de prueba
Caso de prueba | Descripción
Caso de prueba 1 | El robot, una vez cargado, se dirige a la estación de descarga 1.
Caso de prueba 2 | El robot, una vez cargado, se dirige a la estación de descarga 2.
Caso de prueba 3 | El robot, una vez cargado, se dirige a la estación de descarga 3.

### 5.1 Caso de prueba 1

1. El robot inicia su recorrido y registra el código QR [5], que señala el inicio de la estación de carga. Luego, se detiene frente a la estación y espera a que se le suministre la carga. Una vez completado el proceso de carga, continúa su recorrido.
2. Durante el recorrido, el robot registra el código QR [6], que indica la estación de descarga a la que debe dirigirse. Este código es variable y existen tres códigos QR distintos, correspondientes a las tres estaciones de descarga. En el caso de prueba 1, el robot se dirige a la estación de descarga 1.
3. El robot continúa su recorrido tomando la curva. Si durante este tramo se sale momentáneamente de la pista, este comportamiento se considera normal. Después de la curva, detecta el código QR [7].
4. El código QR [7] indica al robot que debe girar a la izquierda para tomar el carril 2, donde se encuentra la estación de descarga 1.
5. El robot gira a la izquierda y se posiciona en el carril
2. En este tramo, detecta el código QR [8], que indica el inicio de la estación de descarga 1.
6. El robot se posiciona en la estación de descarga y espera a que se retire la carga. Una vez completada la descarga, continúa su recorrido por el carril 2 hasta detectar el código QR [9], que indica el final de este carril.
7. Después de detectar el código QR [9], el robot regresa a su posición de partida.

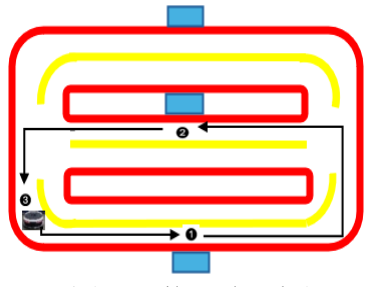
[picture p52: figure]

Fig.15. Recorrido caso de prueba 1

### 5.2 Caso de prueba 2

1. El robot inicia su recorrido y registra el código QR [5], que señala el inicio de la estación de carga. Luego, se detiene frente a la estación y espera a que se le suministre la carga. Una vez completado el proceso de carga, continúa su recorrido.
2. Durante el recorrido, el robot registra el código QR [6], que indica que debe dirigirse a la estación de descarga 2.
3. El robot continúa su recorrido tomando la curva. Después de la curva, detecta el código QR [7].
4. El código QR [7] indica al robot que debe continuar en línea recta para dirigirse a la estación de descarga 2.
5. Al continuar el recorrido, el robot se posiciona en el carril 3. En este tramo, detecta el código QR [10], que indica el inicio de la estación de descarga 2.
6. El robot se posiciona en la estación de descarga y espera a que se retire la carga. Una vez completada la descarga, continúa su recorrido por el carril 3 hasta detectar el código QR [11].
7. Durante el recorrido, detecta el código QR [12], que indica el final del recorrido.
8. Después de detectar el código QR [12], el robot regresa a su posición de partida.

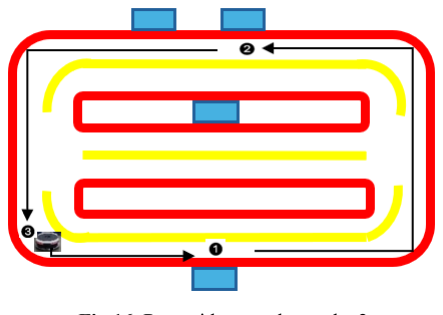
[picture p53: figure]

Fig.16. Recorrido caso de prueba 2

### 5.3 Caso de prueba 3

1. El robot inicia su recorrido y registra el código QR [5], que señala el inicio de la estación de carga. Luego, se detiene frente a la estación y espera a que se le suministre la carga. Una vez completado el proceso de carga, continúa su recorrido.
2. Durante el recorrido, el robot registra el código QR [6], que indica que debe dirigirse a la estación de descarga 3.
3. El robot continúa su recorrido tomando la curva. Después de la curva, detecta el código QR [7].
4. El código QR [7] indica al robot que debe continuar en línea recta para dirigirse a la estación de descarga 3.
5. Al continuar el recorrido, el robot se posiciona en el carril 3, donde detecta el código QR [10], que indica el inicio de la estación de descarga 2. Luego, realiza una pausa, registra el código y continúa su recorrido hacia la estación de descarga 3.
6. El robot registra el código QR [11], que indica el inicio de la estación de descarga 3. Luego, se posiciona en la estación y espera a que se retire la carga. Una vez completada la descarga, continúa su recorrido por el carril 3 hasta detectar el código QR [12], que indica el final del recorrido.
7. Después de detectar el código QR [12], el robot regresa a su posición de partida.

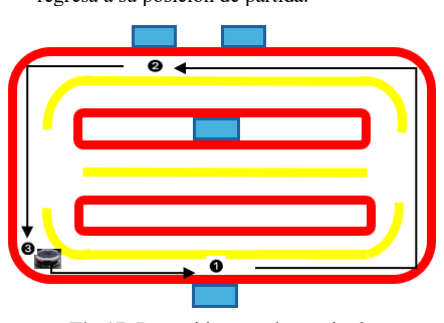
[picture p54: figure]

Fig.17. Recorrido caso de prueba 3

# 6. Características técnicas estándar

Table 2. Características técnicas
Característica | Especificación
Peso máximo carga | 2 Kg
Velocidad nominal | 0,2 m/s
Batería | Lipo turnigy 5000 mAh
Tiempo de servicio y de carga | Hasta 10 h/ Tiempo de carga 2,5 h
Seguridad | Camara frontal IMX219 y sensor frontal de ultrasonido
Inteligencia | Detección y detención frente a obstaculos

# 7. Dimensiones

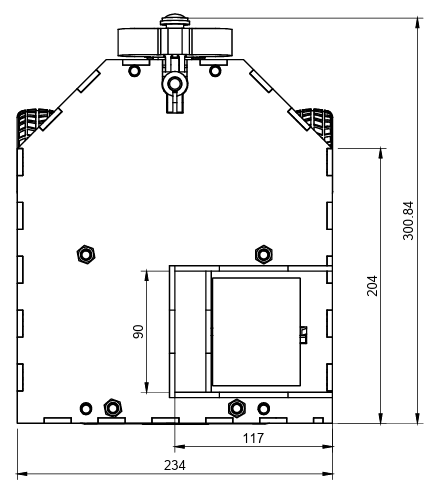
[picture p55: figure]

Fig.18. Medidas vista superior

Fig. 19. Medidas vista frontal

# 8. Inspección y mantenimiento

### 8.1 Limpieza

Limpie periódicamente el chasis, las ruedas, la cámara, el sensor frontal de ultrasonido, el sensor seguidor de línea, la PCB, la Raspberry Pi y los reguladores de voltaje para eliminar el polvo y la suciedad. Para los componentes electrónicos, utilice una brocha seca de cerdas suaves o un paño seco, siempre con el robot apagado y la batería desconectada.
Siga los pasos a continuación para la limpieza interna del robot.
1. Retire las 4 tuercas hexagonales superiores M8 con llave boca fija 12 mm

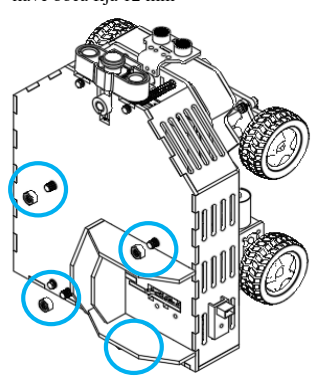
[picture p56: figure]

Fig. 20. Desmonte de tuercas superiores M8

2. Retire la base superior de carga halando hacia arriba.

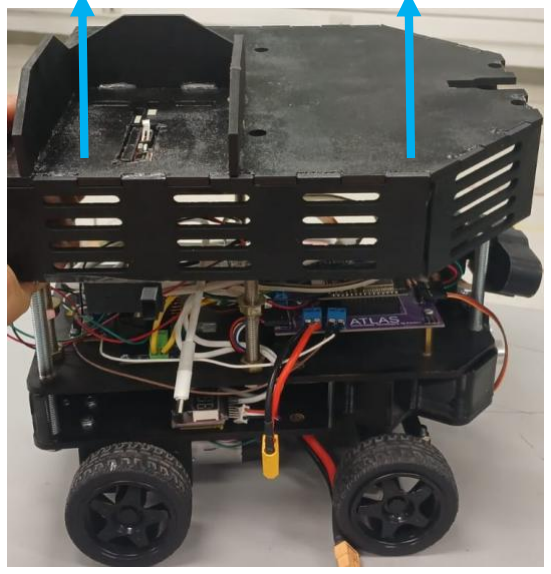
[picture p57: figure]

Fig. 21. Desmontaje de base superior de carga

3. Desconecte el sensor seguidor de línea y el final de carrera de la PCB para mayor facilidad en la limpieza.

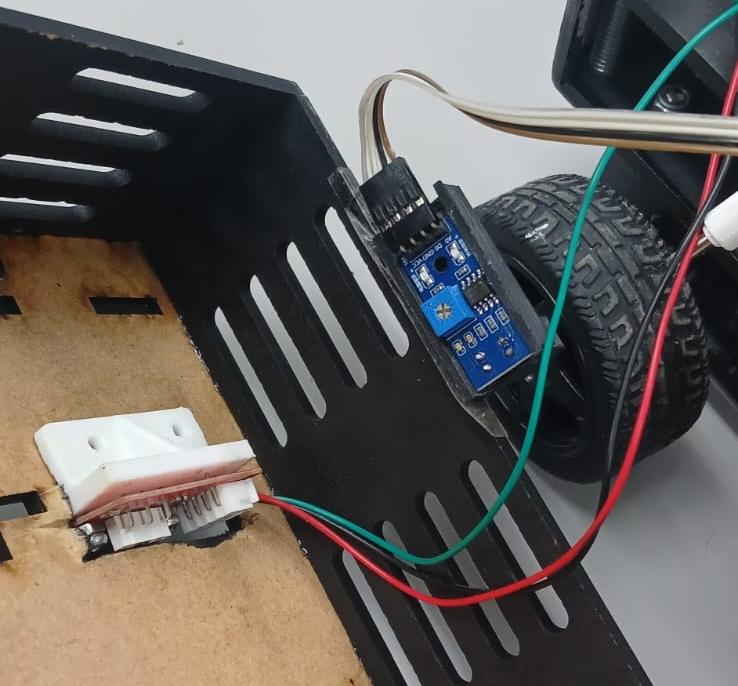
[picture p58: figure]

Fig. 22. Cables del final de carrera y seguidor de línea

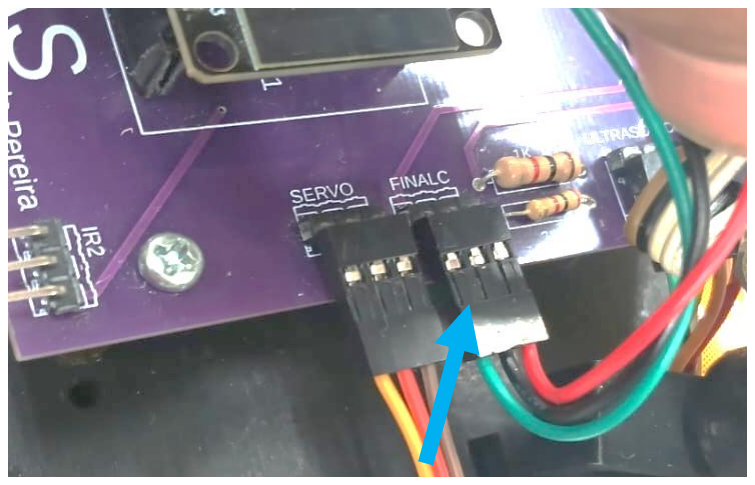
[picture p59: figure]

Fig. 23. Conector final de carrera

Nota: tener precaución al conectar en el mismo orden de colores de la Fig.23.

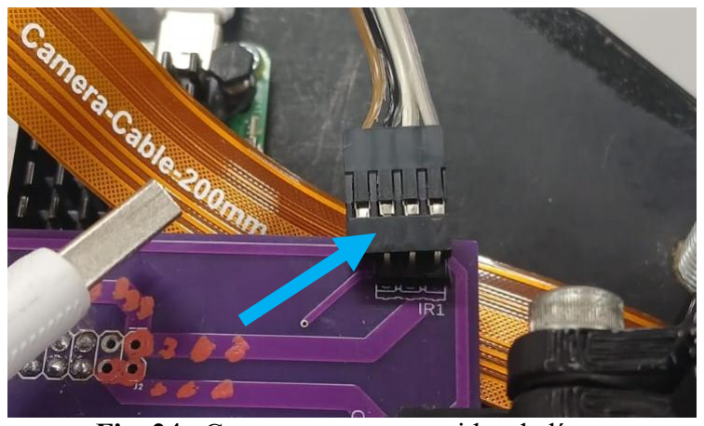
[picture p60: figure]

Fig. 24. Conector sensor seguidor de línea

4. Vuelva a instalar los componentes en el mismo orden inverso al de extracción.

### 8.2 Cuidado de la batería

La batería LiPo debe cargarse únicamente con un cargador adecuado para este tipo de batería. Antes de operar el robot, verifique su voltaje con la alarma LiPo. No utilice el sistema si la batería presenta un nivel inferior al recomendado. Si el robot no va a utilizarse durante un período prolongado, almacene la batería con una carga parcial y en un lugar seguro.

### 8.2.1 Desconexión de la batería

1. Desconecte el conector de la batería XT 60, que se encuentra por el lateral derecho del robot.

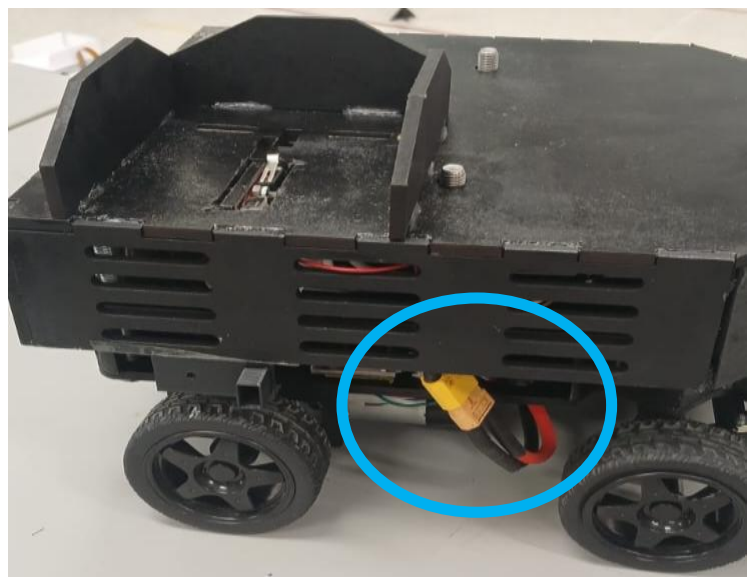
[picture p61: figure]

Fig. 25. Conector XT60 de la batería

2. Lleve el robot hasta el cargador recomendado.

Nota: El cargador recomendado para tu batería LiPo 2S (7.4 V, 5000 mAh) debe ser un cargador balanceado, porque solo estos cargadores cargan cada celda por separado y evitan daños.

3. Conecte el adaptador de balance al cargador.

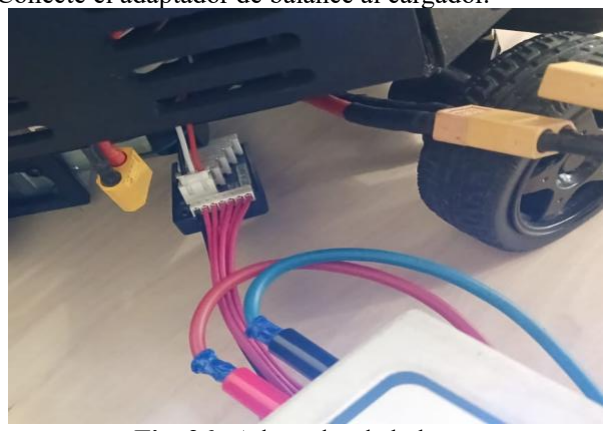
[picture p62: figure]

Fig. 26. Adaptador de balance

4. Conecte el conector blanco de 3 pines de la batería lipo en el puerto 2S del adaptador de balance.

Fig. 27. Conexión en puerto 2S

5. Conecte el conector de la batería XT60 a los cables de conexión que van directamente al borne positivo y negativo del cargador de baterías.

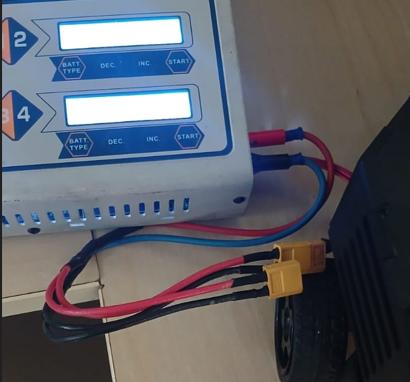
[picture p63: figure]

Fig. 28. Cables de conexión a cargador de la batería

6. En la configuración del cargador de batería se debe seleccionar las siguientes opciones:
- Tipo de batería: Lipo
- Celdas: 2S
- Modo: Balance
- Corriente: 1A

Nota: dejarla cargar hasta llegar a 8,4 V

### 8.3 Inspección de componentes

Revise periódicamente el estado de los cables, conectores, reguladores, motores, sistema de dirección y elementos de fijación. Verifique que no existan conexiones flojas, desgaste mecánico o daños visibles que puedan comprometer la operación del robot.

### 8.3.1 Procedimiento para desmontar ruedas delanteras

### 1. Utilice una llave expansiva y posiciónela en el hexágono

de los acoples delanteros.

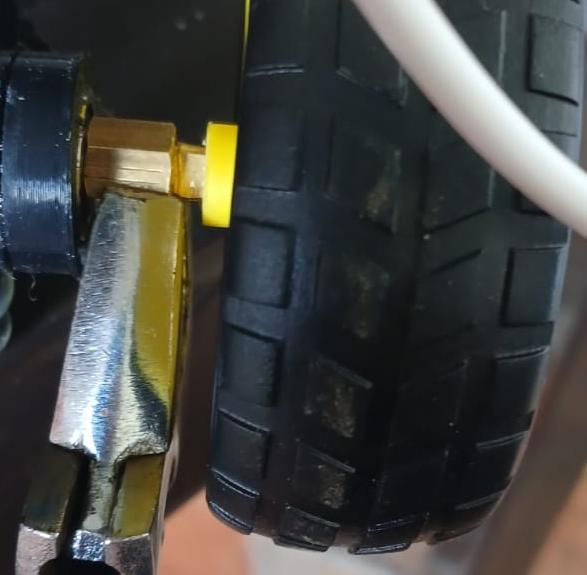
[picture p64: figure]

Fig. 29. Hexágono acoples delanteros

2. Utilice un destornillador de pala y apoyándose en la llave expansiva palanquee la rueda delantera hacia afuera, ya que el cuadrante ingresa con ajuste de interferencia en la rueda delantera.

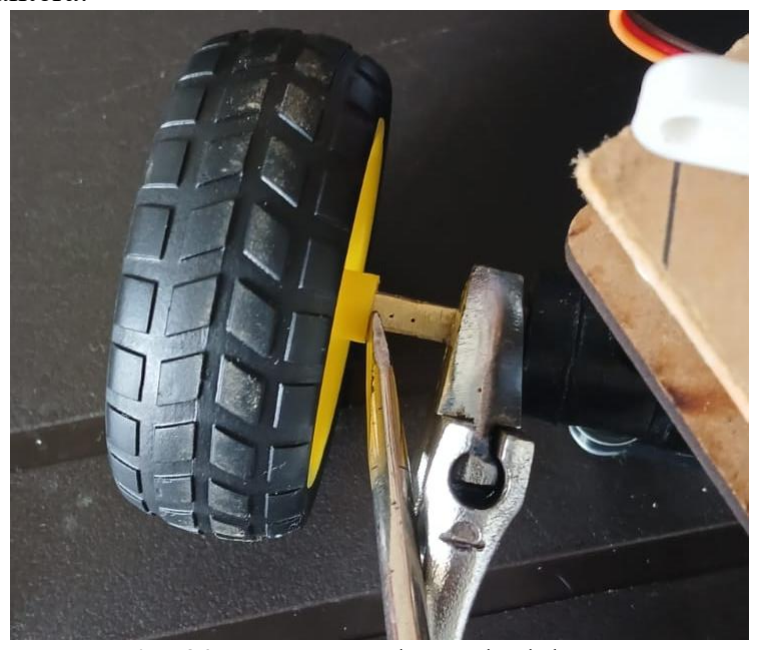
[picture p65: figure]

Fig. 30. Desmonte de rueda delantera

Fig. 31. Rueda delantera por fuera del acople

### 8.3.2 Procedimiento para desmontar ruedas traseras

### 1. Afloje los tornillos prisiones M3 con llave brístol #2 de los

acoples de las ruedas traseras.

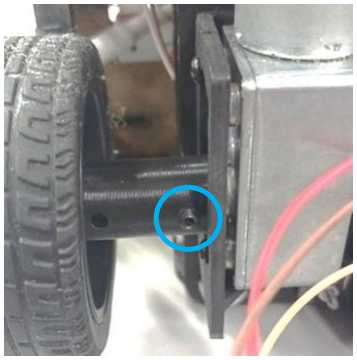
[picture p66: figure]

Fig. 31. Prisionero acople trasero

### 2. Deslice la rueda trasera junto al acople hacia afuera, el

ajuste del acople con el eje del motorreductor es deslizante.

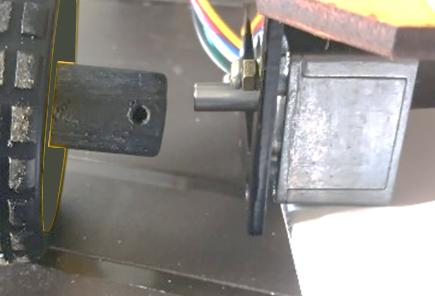
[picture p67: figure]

Fig. 32. Desmonte rueda trasera

### 8.4 Almacenamiento

Cuando el robot no esté en uso, guárdelo en un lugar seco, limpio y protegido de la luz solar directa, la humedad y las temperaturas extremas. Antes de almacenarlo, asegúrese de que la batería esté desconectada o en condiciones seguras de carga.

9. Solución | de

# problemas

Si encuentra algún problema con su Robot Atlas consulte las siguientes opciones para la solución de problemas:

### 9.1. El robot no enciende

- Verifique la conexión de la batería y asegúrese de que esté correctamente instalada.
- Confirme que la batería tenga suficiente carga.
- Compruebe que el interruptor de encendido esté en la posición ON.

### 9.2. Fallos en el funcionamiento del motor

- Revise las conexiones del motor y asegúrese de que estén firmes y sin falsos contactos.
- Inspeccione si existe alguna obstrucción física que limite o impida el movimiento de las ruedas.

# 10. Especificaciones técnicas

Alimentación

Voltaje de entrada batería: 6,6 V (mínimo seguro) y 8,4 V (máximo cargado).

Sensores

- Sensor ultrasonido HC-SR04
- Modulo seguidor de línea TRCT5000

Comunicación

- Comunicación Raspberry pi-ESP 32, USB.
- Comunicación PC-Rasberry pi: (WIFI) Protocolo: SSH
Componentes eléctricos y electrónicos.
- ESP 32S Conector tipo C
- Driver motor DC TB6612FNG marca Pololu.
- 2 motorreductores helicoidal JGY-370 6 V 100RPM con encoder.
- Regulador de voltaje DC-DC 8A XL4016E.
- Regulador de voltaje LM2596
- Cámara IMX219 con cable cinta
- Raspberry PI 5
- Final de carrera, Endstop Impresora 3D
- Micro servo MG90S, piñoneria metálica
- Salva lipo de 1s a 8s con indicador sonora y visual
- Batería Turnigy 5000mAh 2S 40C Lipo Pack w/XT-60

- Conector XT60 Macho con cable Siliconado 14AWG, 10cm

Componentes mecánicos.

- Rueda común goma diámetro externo 65 mm.

# 11. Anexos

### 11.1 Sistema Ackermann

Table 3. Componentes sistema Ackermann
Item | Nombre | Cantidad
1 | Rueda común 65 mm | 4
2 | Acople delantero | 1
3 | Rodamiento 605 | 2
4-8 | Soporte giratorio Ack | 2
5 | Tornillo bristol M5X10 mm | 2
6 | Tornillo bristol M5x55 mm | 4
7 | Barra rigidez soportes giratorios | 1
9 | Tuercas hexagonales M5 | 7
10 | Soporte servo RH | 1
11 | Soporte servo LH | 1
12 | Bujes rigidez | 2
13 | Brazo servo | 1
14 | Barra dirección | 1
15 | Tornillo bristol M5x15 | 3
16 | Micro servo MG90S | 1
17 | Tornillos cabeza lenteja M3X15 con tuerca | 4

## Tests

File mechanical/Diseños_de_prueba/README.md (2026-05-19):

# 🧪 Diseños de prueba

Esta carpeta contiene los primeros prototipos mecánicos y modelos experimentales desarrollados durante la etapa inicial del robot móvil **G7ACKER**.

El objetivo principal de esta sección fue validar diferentes conceptos mecánicos antes de implementar las versiones finales utilizadas en el robot.

Durante esta etapa se realizaron pruebas relacionadas con:

- Diseño del chasis
- Sistema de dirección
- Soportes de cámara
- Integración de ruedas
- Mecanismos Ackerman
- Sistema de tracción
- Distribución estructural

Cada subcarpeta contiene archivos de diseño CAD y modelos para impresión 3D.

---

# 📂 Estructura de archivos

Dentro de cada subcarpeta se incluyen principalmente dos tipos de archivos:

| Extensión | Descripción |
|---|---|
| `.f3d` | Archivo de diseño editable de Autodesk Fusion 360 |
| `.stl` | Archivo de malla 3D utilizado para impresión 3D |

Los archivos `.f3d` permiten modificar y editar el diseño mecánico, mientras que los `.stl` corresponden a versiones listas para fabricación mediante impresión 3D.

---

# 📁 bases

La carpeta `bases` contiene los primeros diseños del chasis principal del robot.

Estos modelos fueron utilizados para evaluar:

- Tamaño general del robot
- Distribución de componentes
- Espacio para electrónica
- Ubicación de sensores
- Soporte estructural

## 📄 Archivos principales

| Archivo | Descripción |
|---|---|
| `base_piso_3_carga.f3d` | Diseño editable de la base principal |
| `base_piso_3_carga.stl` | Modelo STL para impresión 3D |
| `base_v1.f3d` | Primera versión experimental del chasis |
| `base_v1.stl` | Modelo STL correspondiente |

---

# 📁 Camara

La carpeta `Camara` contiene prototipos iniciales del sistema de soporte para la cámara del robot.

Estos diseños permitieron realizar pruebas de:

- Ángulo de visión
- Altura de montaje
- Estabilidad mecánica
- Integración con la Raspberry Pi

## 📄 Archivos principales

| Archivo | Descripción |
|---|---|
| `base_camara.f3d` | Diseño base del soporte de cámara |
| `base_camara.stl` | Modelo imprimible del soporte |
| `pilar_camara.f3d` | Soporte vertical de la cámara |
| `pilar_camara.stl` | Modelo STL del pilar |

---

# 📁 direccion_v1

La carpeta `direccion_v1` contiene la primera versión funcional del sistema de dirección mecánica del robot.

Este diseño se basó en un mecanismo tipo Ackerman para mejorar la estabilidad de giro y el control de trayectoria.

Durante esta etapa se desarrollaron componentes como:

- Acoples de rueda
- Barras de dirección
- Engranajes
- Soportes Ackerman
- Piñones
- Brazos de dirección
- Integración con servomotor

## 📄 Componentes principales

| Componente | Función |
|---|---|
| `ACOPLE_RUEDA_*` | Acople mecánico entre rueda y sistema de dirección |
| `BARRA_DIRECCION` | Transmisión del movimiento de giro |
| `BARRA_SERVO` | Conexión mecánica con el servomotor |
| `BRAZO_DIRECCION` | Brazo articulado de dirección |
| `ENGRANAJE_BRAZO` | Sistema de transmisión mecánica |
| `PIÑON_SERVO` | Piñón conectado al servomotor |
| `SOPORTE_ACKERMAN_BASE` | Base estructural del mecanismo Ackerman |

Cada componente incluye su versión editable `.f3d` y su modelo `.stl`.

---

# 📁 direccion_v2

La carpeta `direccion_v2` contiene una segunda iteración del sistema de dirección, desarrollada para mejorar:

- Precisión del giro
- Resistencia estructural
- Estabilidad mecánica
- Integración entre ruedas y servo

En esta versión se realizaron ajustes sobre:

- Barras superiores
- Pilares laterales
- Acoples mecánicos
- Unión de dirección

## 📄 Componentes principales

| Componente | Función |
|---|---|
| `ACOPLE_RUEDA_PILAR` | Unión entre rueda y soporte vertical |
| `BARRA_DIRECCION_V2` | Segunda versión de la barra de dirección |
| `BARRA_UNION_INFERIOR` | Unión estructural inferior |
| `BARRA_UNION_SUPERIOR` | Unión estructural superior |
| `PILAR_DER` | Pilar lateral derecho |
| `PILAR_IZQ` | Pilar lateral izquierdo |

Todos los archivos se encuentran disponibles tanto en formato editable `.f3d` como en formato imprimible `.stl`.

---

# 📁 traccion_v1

La carpeta `traccion_v1` contiene los primeros diseños relacionados con el sistema de tracción del robot.

Estos modelos fueron utilizados para probar:

- Montaje de motores
- Integración de ruedas
- Distribución de fuerza
- Soporte mecánico de transmisión

## 📄 Archivos

| Archivo | Descripción |
|---|---|
| `traccion_v1.md` | Documento descriptivo del sistema de tracción |

---

# 🛠️ Fabricación de piezas

Los modelos STL incluidos en esta carpeta fueron diseñados para fabricación mediante impresión 3D utilizando tecnología FDM.

Esto permitió:

- Construcción rápida de prototipos
- Modificación iterativa de diseños
- Validación física de componentes
- Reducción de costos de desarrollo

---

# ⚙️ Flujo de desarrollo

El proceso de diseño mecánico siguió una metodología iterativa basada en:

1. Diseño CAD en Fusion 360.
2. Exportación de modelos STL.
3. Impresión 3D de prototipos.
4. Ensamble mecánico.
5. Pruebas físicas.
6. Correcciones estructurales.
7. Desarrollo de nuevas versiones.

Las diferentes versiones almacenadas en esta carpeta reflejan la evolución del sistema mecánico del robot G7ACKER.

---

# 🚀 Importancia dentro del proyecto

Los diseños de prueba permitieron validar el comportamiento mecánico del robot antes de fabricar la versión final del sistema.

Gracias a esta etapa fue posible:

- Detectar fallas mecánicas tempranas
- Mejorar la estabilidad
- Optimizar el sistema de dirección
- Ajustar dimensiones estructurales
- Facilitar la integración electrónica

Esta fase fue fundamental para el desarrollo exitoso del robot móvil autónomo G7ACKER.

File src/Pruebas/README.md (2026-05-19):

# 🧪 Carpeta de Pruebas

Esta carpeta contiene el conjunto de pruebas, validaciones y prototipos desarrollados durante la construcción del robot móvil autónomo G7ACKER.

El objetivo principal de esta sección del proyecto fue verificar individualmente el funcionamiento de cada subsistema antes de integrarlos en la arquitectura final del robot.

Las pruebas incluyen:

- Comunicación serial
- Visión artificial
- Cámara Raspberry Pi
- Sensores
- Motores DC
- Encoders
- Servomotores
- Sensores ultrasónicos
- Sensores infrarrojos
- Finales de carrera

Esta metodología permitió desarrollar el sistema de manera modular, facilitando:

- Depuración
- Calibración
- Ajuste de parámetros
- Integración progresiva
- Validación de hardware

---

# 📂 Contenido de la carpeta

Dentro de esta carpeta se encuentran distintos scripts y programas de prueba utilizados durante el desarrollo del robot.

Los principales módulos evaluados fueron:

- Cámara y procesamiento de imagen
- Comunicación Raspberry ↔ ESP32
- Control de motores
- Lectura de sensores
- Movimiento del servomotor
- Medición de velocidad
- Detección de obstáculos

Cada archivo corresponde a una prueba específica del sistema.

---

# 📷 Prueba de Cámara

## `prueba_camara.py`

Este archivo implementa el sistema de visión artificial utilizado para detectar carriles y generar comandos de navegación para el robot.

El sistema utiliza:

- Picamera2
- OpenCV
- Flask
- Comunicación serial con ESP32

Las funciones principales incluyen:

- Captura de video en tiempo real
- Corrección automática de brillo
- Ajuste de color y saturación
- Detección de líneas amarillas
- Detección de bordes negros y rojos
- Cálculo del centro del carril
- Generación de comandos de movimiento

El sistema procesa la imagen utilizando espacios de color HSV y operaciones morfológicas para mejorar la estabilidad de detección.

Además, implementa un servidor Flask para visualizar el procesamiento desde el navegador en tiempo real.

---

# 📸 Captura de Imagen

## `foto_prueba.py`

Este script fue utilizado para verificar el funcionamiento básico de la cámara conectada a la Raspberry Pi.

El código realiza:

- Inicialización de Picamera2
- Captura de una fotografía
- Almacenamiento automático de la imagen

Esta prueba permitió validar:

- Conexión física de la cámara
- Configuración del sistema
- Funcionamiento del sensor
- Acceso desde Python

---

# 🔌 Pruebas de Comunicación Serial

## `prueba_comunicacion_esp32.ino`

Este programa implementa una prueba básica de recepción serial en el ESP32.

El sistema:

- Recibe caracteres enviados desde la Raspberry Pi
- Enciende o apaga el LED integrado
- Imprime mensajes en el monitor serial

Los comandos implementados son:

| Comando | Acción |
|---|---|
| `a` | Encender LED |
| `x` | Apagar LED |

Esta prueba permitió verificar:

- Comunicación USB serial
- Baudrate
- Recepción de datos
- Funcionamiento básico del ESP32

---

## `prueba_comunicacion_raspberry.py`

Este script permite enviar comandos manuales desde la Raspberry Pi utilizando el teclado.

El sistema:

- Lee teclas en tiempo real
- Envía caracteres mediante serial
- Permite controlar manualmente el robot

Los comandos disponibles son:

| Tecla | Acción |
|---|---|
| `a` | Adelante |
| `r` | Atrás |
| `d` | Detenido |
| `i` | Izquierda |
| `e` | Derecha |

Esta prueba fue utilizada para validar la integración entre Raspberry Pi y ESP32 antes de implementar navegación autónoma.

---

# 🔘 Prueba de Final de Carrera

## `prueba_final_carrera.py`

Este script implementa la lectura de un sensor de final de carrera conectado a la Raspberry Pi utilizando la librería `gpiozero`.

El sistema detecta:

- Activación del interruptor
- Liberación del interruptor

La prueba permitió validar:

- Lectura digital de entradas GPIO
- Eventos de interrupción
- Respuesta del sistema ante contacto físico

Este sensor se utiliza posteriormente para detectar posiciones límite y eventos mecánicos dentro del robot.

---

# 📡 Prueba de Sensor IR

## `prueba_ir.py`

Este archivo implementa la lectura directa de un sensor infrarrojo utilizando la librería `lgpio`.

El sistema realiza:

- Lectura continua del GPIO
- Visualización del estado lógico del sensor
- Monitoreo en tiempo real

La prueba permitió verificar:

- Funcionamiento del sensor IR
- Compatibilidad con Raspberry Pi 5
- Lectura digital estable

Este sensor se utiliza posteriormente para detección de objetos o activación de eventos específicos dentro del recorrido autónomo.

---

# ⚙️ Pruebas de Motores

## `prueba_motores_ppr.ino`

Este programa fue desarrollado para calcular los pulsos por revolución (PPR) de los encoders instalados en los motores DC.

El sistema:

- Hace girar el motor
- Cuenta pulsos mediante interrupciones
- Detiene la medición manualmente
- Muestra el total de pulsos registrados

Esta prueba permitió obtener los valores reales de calibración de los encoders.

---

## `prueba_motores_velocidad.ino`

Este archivo implementa el cálculo de:

- RPM
- Velocidad angular
- Velocidad lineal

Utilizando:

- Lectura de encoder
- Conversión matemática
- Medición temporal

Los resultados obtenidos fueron utilizados posteriormente para calibrar el sistema de control de movimiento del robot.

---

# 🎯 Prueba de Servomotor

## `prueba_servo.ino`

Este programa permite controlar manualmente el servomotor encargado de la dirección del robot.

El sistema recibe comandos seriales y posiciona el servo en distintos ángulos:

| Comando | Dirección |
|---|---|
| `d` | Centro |
| `s` | Derecha |
| `f` | Izquierda |

La prueba permitió:

- Calibrar ángulos
- Ajustar límites mecánicos
- Verificar estabilidad del servo

---

# 📏 Pruebas de Sensor Ultrasónico

## `prueba_ultrasonido_gpiozero.py`

Este script implementa medición de distancia utilizando la librería `gpiozero`.

El sistema:

- Calcula distancia en centímetros
- Detecta obstáculos
- Envía comandos seriales al ESP32

Comportamiento implementado:

| Distancia | Acción |
|---|---|
| ≤ 30 cm | Detener |
| > 30 cm | Avanzar |

Esta versión ofrece una implementación más sencilla y estable para Raspberry Pi.

---

## `prueba_ultrasonido_rpigpio.py`

Esta versión implementa la lectura manual del sensor ultrasónico utilizando `RPi.GPIO`.

El sistema controla directamente:

- Pulso TRIG
- Lectura ECHO
- Cálculo temporal del eco

Esta prueba permitió comprender el funcionamiento interno del sensor HC-SR04 y validar mediciones manuales.

---

# 🧩 Metodología de Desarrollo

El desarrollo del robot se realizó mediante una estrategia modular basada en pruebas individuales.

Cada subsistema fue validado de forma independiente antes de integrarse en el sistema principal.

Esta metodología permitió:

- Reducir errores
- Aislar fallos
- Ajustar parámetros
- Validar hardware
- Mejorar estabilidad del sistema final

---

# 🚀 Función dentro del proyecto

La carpeta de pruebas representa el proceso experimental y de validación utilizado durante el desarrollo del robot móvil autónomo G7ACKER.

Gracias a estas pruebas fue posible:

- Diseñar el sistema final
- Calibrar sensores
- Ajustar motores
- Validar comunicación
- Construir la arquitectura autónoma del robot

Cada archivo refleja una etapa importante dentro del proceso de desarrollo e integración del sistema robótico.

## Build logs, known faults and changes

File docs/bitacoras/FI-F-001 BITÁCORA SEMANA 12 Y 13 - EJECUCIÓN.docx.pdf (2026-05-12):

### INGENIERÍA MECATRÓNICA

SEMESTRE INTEGRADOR | CÓDIGO | FI-F-001
BITÁCORA | VERSIÓN | 2

IDENTIFICACIÓN DEL PROYECTO

NOMBRE DEL PROYECTO: ATLAS

INTEGRANTES DEL EQUIPO
NOMBRE | APELLIDOS | CÓDIGO | ROL EN EL PROYECTO
VANESA | GALEANO FRANCO | 1109292401 | MECÁNICA
NOMBRE | APELLIDOS | CÓDIGO | ROL EN EL PROYECTO
SOFIA SALOMÉ | ESPITIA JIMENEZ | 1080046389 | DISEÑADORA
NOMBRE | APELLIDOS | CÓDIGO | ROL EN EL PROYECTO
JULIÁN ANDRÉS | GARCIA | 1088004478 | ELECTRÓNICO
NOMBRE | APELLIDOS | CÓDIGO | ROL EN EL PROYECTO
JOSE LISANDER | HURTADO | 1088028747 | PROGRAMADOR

FECHA DE ENTREGA (DD/MM/AA): 01/05/2026

SEMANA NO: 10 Y 12

RESPONSABLE DEL REGISTRO: Sofía Salomé Espitia Jiménez

ETAPA/FASE DEL PROYECTO: Lectura de QRs e Integración de sistemas completos.

PLANEACIÓN

OBJETIVOS (Definidos en la reunión de planeación):

1. Implementar la conexión y montaje de sensores en el prototipo del robot, verificando su correcto funcionamiento en protoboard y su adecuada integración física en el chasis.
2. Desarrollar los scripts de seguimiento de línea, detección de obstáculos y lectura de códigos QR, asegurando su correcto funcionamiento.
3. Integrar los sistemas mecánicos, electrónicos y de programación del robot ATLAS durante las semanas 12 y 13, garantizando su ensamblaje completo, funcionalidad conjunta y correcta comunicación.
4. Validar el desempeño del robot mediante pruebas en circuito, comprobando su capacidad de navegación autónoma, detección de obstáculos y lectura de códigos QR en condiciones controladas.
5. Documentar el proceso de desarrollo e integración del proyecto en el repositorio y la bitácora correspondiente, con coherencia, actualización continua y organización de la información.

SEMESTRE INTEGRADOR | CÓDIGO | FI-F-001
BITÁCORA | VERSIÓN | 2
ACTIVIDAD | FECHA DE INICIO | FECHA FINAL | MATERIALES | PRESUPUEST O | RIESGOS POTENCIALES | ALTERNATIVAS | ENTREGABLE | RESPONSABLE
Conexión de sensores a la protoboard | 20-04-2 026 | 20-04-2026 | Sensores Infrarrojos, protoboard | $ 219.672 | Malas conexiones de sensores y funcionamient o irregular de los mismos. | Probar con diferentes conexiones y pines | Sensores funcionand o con protoboard. | Julián.
Integración de sensores al chasis | 20-04-2026 | 21-04-2 026 | Sensores infrarrojos, chasis, fusión, impresora 3D | $ 439.344 | Espacio o distribución para la ubicación insuficiente, soportes ineficientes. | Hacer ensamblaje en fusión y verificar las tolerancias al momento de imprimir los soportes de sensores. | Sensores integrados al chasis del robot | Julián.
Programa de seguimiento de línea y detección frente a obstáculos mejorado | 20-04-2 026 | 22-04-2 026 | Computado r, robot prototipo, Raspberry pi 5, Visual Studio Code | $ 878.688 | Envío incorrecto de la señal al servomotor del ackerman, haciendo que no garantice una trayectoria recta | Verificar alimentació n del servo y envío de señal, de ser necesario cambiar de servomotor | Script de seguimient o de línea y detección de obstáculos completo | Jose
Código de lectura de QRs | 20-3-20 26 | 24-3-20 26 | Computado r, robot prototipo, Raspberry pi 5, Visual Studio Code | $ 878.688 | Identificación nula o incorrecta del QR por medio de la cámara | Probar librerías de visión para garantizar la lectura correcta | Script de lectura de códigos QRs completo | Vanesa
Evasión de obstáculos | 22-04-2 026 | 24-03-2 026 | Computado r, robot prototipo, Raspberry pi 5, Visual Studio Code | $ 878.688 | Errores en el funcionamient o de la dirección ackerman y velocidad de motores. | Verificar rango de movilidad y señal de envío. | Script de ovación de obstáculo completo | Jose
Integración total - Mecánica | 27-3-20 26 | 30-04-2 026 | Bases del robot, Cubierta, tornillería, herramienta s | $ 439.344 | Problemas al momento de corte de las bases y el ensamble general | Verificar bien la piezas antes de mandara cortar y/o repetir la pieza | Estructura del robot completam ente armada | Julián

SEMESTRE INTEGRADOR | CÓDIGO | FI-F-001
BITÁCORA | VERSIÓN | 2
ACTIVIDAD | FECHA DE INICIO | FECHA FINAL | MATERIALES | PRESUPUEST O | RIESGOS POTENCIALES | ALTERNATIVAS | ENTREGABLE | RESPONSABLE
Integración total - Electrónica | 27-03-2 026 | 30-04-2 026 | Computado r, Fusion, PCB | $ 439.344 | Errores de conexiones, elementos quemados, pines inservibles | Revisar esquemátic o, cambiar elementos electrónicos , utilizar otra PCB | Distribución electrónica completa y funcional | Vanesa
Integración total - Programación | 27-03-2 026 | 30-04-2 026 | Computado r, robot prototipo, Raspberry pi 5, Visual Studio Code | $ 439.344 | Bugs del código y de comunicación al momento de unificar todos los scripts. | Unificación secuencial, documentad a y experimenta l, para evitar errores. | Scripts en repositorio y cargados en los microproce sadores. | Jose
Integración total - Documentación | 27-04-2 026 | 30-04-2 026 | Computado r, Google Docs, GitHub | $ 219.672 | Inconsistencia s en información, información incompleta en el repositorio | Validación con el equipo, actualizació n constante del repositorio | Repositorio completo y organizado | Sofía
Pruebas para validar la funcionalidad principal del robot | 01-05-2 026 | 01-05-2 026 | Robot completo y funcional, circuito de pruebas | $ 878.688 | Errores en navegación autónoma y toma de decisiones en tiempo real | Actualizació n / Validación de códigos en correcto funcionamie nto y verificación de sistema de dirección | Robot funcional en circuito de pruebas básico | Vanesa
Bitácora 6 -Planeación semana 14 y 15 | 01-05-2 026 | 01-05-2 026 | Computado r, Google Docs | $ 219.672 | Inconsistencia en la información | Validación con el equipo | Bitácora 6 -Planeación semana 14 y 15 | Sofía

SEMESTRE INTEGRADOR | CÓDIGO | FI-F-001
BITÁCORA | VERSIÓN | 2

EJECUCIÓN

ACTIVIDAD | FECHA INICIO | FECHA FIN | OPORTUNIDADES DE MEJORA O DESAFÍOS ENCONTRADOS | ACCIONES CORRECTIVAS O DE MEJORA | ESTADO DE ENTREGABLE | RESPONSABLE
Conexión de sensores a la protoboard | - - - | - - - | Se evidenció que con el reconocimiento de la cámara fue suficiente para garantizar un correcto seguimiento de línea. | Probar de manera modular y anticipada los equipos y elementos con los que se dispone antes de realizar una compra apresurada. | No se realizó | Julián.
Integración de sensores al chasis | - - - | - - - | Se evidenció que con el reconocimiento de la cámara fue suficiente para garantizar un correcto seguimiento de línea. | - - - | No se realizó | Julián.
Programa de seguimiento de línea y detección frente a obstáculos mejorado | 20-04-2026 | 22-04-2026 | Ajuste inestable en la trayectoria y respuesta del sistema ante cambios de señal y condiciones del entorno. | Optimizar la calibración de sensores y servomotor, y realizar pruebas iterativas en diferentes escenarios. | Completado | Jose
Código de lectura de QRs | 20-3-2026 | 24-3-2026 | Dificultades en la detección precisa del QR debido a variaciones de iluminación y ángulo de la cámara. | Ajustar parámetros de la cámara y librerías de visión, y validar la lectura en distintos entornos controlados. | Completado | Vanesa
Evasión de obstáculos | - - - | - - - | No se realizó como actividad particular, si no de manera paralela dentro de la lógica del robot. | - - - | No se realizó | Jose
Integración total -Mecánica | 27-3-2026 | - - - | Dificultad en la integración del chasis con respecto a las bases del robot, debido a que en un inicio no se pensó en un tipo de carcasa en particular, por lo cual esta debe adaptarse al diseño de las bases y no se | La situación generó un retraso con los itinerarios, por lo que no fue posible terminar su integración total en las semanas previstas, en un futuro se opta por realizar una planeación más realista pensada en las posibles | En proceso | Julián

SEMESTRE INTEGRADOR | CÓDIGO | FI-F-001
BITÁCORA | VERSIÓN | 2
| | | desarrolló en paralelo. | dificultades que se puedan presentar.
Integración total -Electrónica | 27-03-2026 | 30-04-2026 | Se realizó una unificación indebida entre 2 fuentes de alimentación diferentes, que resultó en la inhabilitación de un pin de la raspberry, adicionalmente, se aliento el módulo de final de carrera al voltaje inadecuado, sin embargo cumple con el funcionamiento de todas formas | Verificar de manera más precisa y detallada, antes de mandar a fabricar la PCB, ya que si bien no se presentaron errores de gravedad, si se perdió la oportunidad de optimizar varios procesos | Completado | Vanesa
Integración total -Programación | 27-03-2026 | - - - | Se completaron los códigos de manera modular, sin embargo no se logró realizar una integración total de estos, ya que el robot en el momento no cuenta con la programación necesaria para realizar todo el circuito leyendo y entendiendo las indicaciones de los QRs. | La situación generó un retraso con los itinerarios, por lo que no fue posible terminar su integración total en las semanas previstas, en un futuro se opta por realizar una planeación más realista pensada en las posibles dificultades que se puedan presentar. | En proceso | Jose
Integración total -Documentació n | - - - | - - - | No se realizó la actividad prevista ya que, la fecha de entrega para la misma se proyecta para dentro de 2 semanas, por lo que se opta priorizar el desarrollo de otras actividades. | Al momento de realizar el cronograma, tener presente y verificar las fechas de los entregables, para evitar confusiones. | No se realizó | Sofía
Pruebas para validar la funcionalidad principal del robot | - - - | - - - | No se realizó ya que era necesario contar con la implementación total de la programación y la parte mecánica, actividades que no se lograron terminar en estas semanas. | En un futuro se opta por realizar una planeación más realista pensada en las posibles dificultades que se puedan presentar. | No se realizó | Vanesa
Bitácora 6 -Planeación semana 14 y 15 | 01-05-2026 | 01-05-2026 | Ninguno | Ninguno | Completado | Sofía

SEMESTRE INTEGRADOR | CÓDIGO | FI-F-001
BITÁCORA | VERSIÓN | 2

ANÁLISIS DE CAUSA RAÍZ DESAFÍOS ENCONTRADOS:

Durante la ejecución de las semanas 12 y 13 se identificó que varias actividades no se realizaron o quedaron en proceso debido principalmente a una planeación poco alineada con la complejidad real del proyecto. En particular, la integración mecánica y de programación presentó retrasos ya que no se desarrollaron de manera paralela desde etapas tempranas, lo que generó una dependencia entre actividades y afectó el cronograma. Adicionalmente, se evidenció una toma de decisiones tardía en cuanto al uso de tecnologías, como el reemplazo de sensores por visión con cámara, lo que llevó a descartar actividades previamente planeadas.

También se presentaron dificultades técnicas en la integración electrónica, como errores en la alimentación y conexiones, lo cual, aunque fue solucionado, reflejó una falta de validación previa detallada antes de la implementación.

Por otra parte, actividades como pruebas funcionales y documentación no se ejecutaron debido a la priorización de tareas críticas y a la dependencia de avances no completados en mecánica y programación. En conclusión, la causa raíz se asocia a deficiencias en la planeación, integración temprana de sistemas y gestión del tiempo frente a la complejidad del proyecto.

EVIDENCIA (FOTOGRAFÍA Y ENLACE A REPOSITORIO):

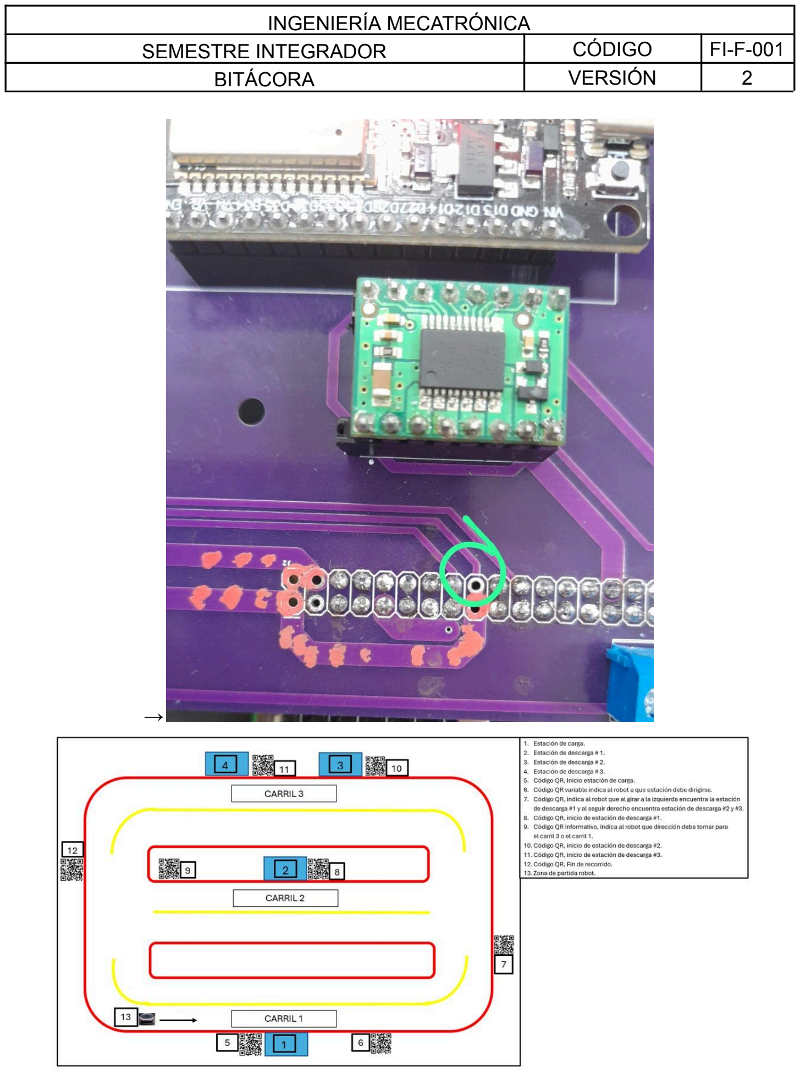
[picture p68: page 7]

SEMESTRE INTEGRADOR | CÓDIGO | FI-F-001
BITÁCORA | VERSIÓN | 2

→

SEMESTRE INTEGRADOR | CÓDIGO | FI-F-001
BITÁCORA | VERSIÓN | 2

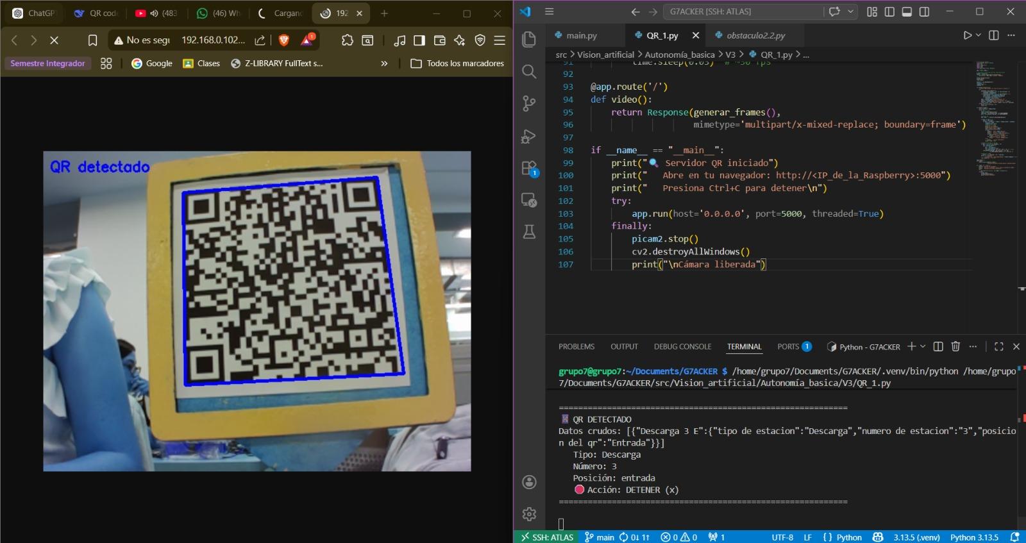
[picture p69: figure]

MATERIALES | CANT. | UNIDAD DE MEDID A | COSTO UNITARIO SIN IVA | IVA | COSTO TOTAL | JUSTIFICACIÓN
Regleta macho en ángulo | 2 | 1x40 | $ 1 458 | $ 684 | $ 3 600 | Elementos necesarios para la PCB
Regleta hembra | 3 | 1x40 | $ 972 | $ 684 | $ 3 600 | Elementos necesarios para la PCB
Bornera Azul | 8 | 2 pines | $ 486 | $ 912 | $ 4 800 | Elementos necesarios para la PCB
Tuercas M3 | 3 | 3x10 mm | $ 810 | $ 570 | $ 3 000 | Elementos necesarios para la implementación mecánica
Tornillo estrella M3 | 2 | 3x20 mm | $ 1 458 | $ 684 | $ 3 600 | Elementos necesarios para la implementación mecánica
Tornillo estrella M3 | 1 | 3x10 mm | $ 1 215 | $ 285 | $ 1 500 | Elementos necesarios para la implementación mecánica
Separador bronce | 6 | 6x12 | $ 810 | $ 1 140 | $ 6 000 | Elementos necesarios para la implementación mecánica
Separador bronce | 2 | 6x20 | | | $ 2 400 | Elementos necesarios para la implementación mecánica

SEMESTRE INTEGRADOR | CÓDIGO | FI-F-001
BITÁCORA | VERSIÓN | 2
COMPROMISOS | RESPONSABLE | FECHA DE INICIO | FECHA FIN | APRENDIZAJES CLAVE
Realizar una planeación más realista, integrando desde etapas tempranas los componentes mecánicos, electrónicos y de programación, además de validar previamente decisiones técnicas y cronogramas para evitar retrasos y reprocesos. | Sofía | 02/05/2026 | 16/05/2026 | Importancia de la integración paralela de sistemas, validación previa de diseños y decisiones tecnológicas, y establecimiento de cronogramas ajustados a la complejidad real del proyecto.

OBSERVACIONES DOCENTES

OBSERVACIÓN | FECHA | DOCENTE

CONTROL DE CAMBIOS
ESPACIO SOLO PARA CAMBIOS DEL FORMATO

SEMESTRE INTEGRADOR | CÓDIGO | FI-F-001
BITÁCORA | VERSIÓN | 2
RESPONSABLE DEL CAMBIO | JUSTIFICACIÓN DEL CAMBIO | DESCRIPCIÓN DEL CAMBIO | FECHA DE CAMBIO | NÚMERO DEL CAMBIO
Angie Tatiana Rengifo Oviedo | Se encontró que el formato anterior le faltaba información y era confuso para el proceso de ABP | Modificación de parámetros en la documentación de la ejecución. | 30/01/2026 | Versión 2

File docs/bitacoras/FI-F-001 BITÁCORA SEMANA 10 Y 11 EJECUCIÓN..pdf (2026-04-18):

## INGENIERÍA MECATRÓNICA

SEMESTRE INTEGRADOR | CÓDIGO | FI-F-001
BITÁCORA | VERSIÓN | 2

### IDENTIFICACIÓN DEL PROYECTO

### NOMBRE DEL PROYECTO: ATLAS

### INTEGRANTES DEL EQUIPO

NOMBRE | APELLIDOS | CÓDIGO | ROL EN EL PROYECTO
VANESA | GALEANO FRANCO | 1109292401 | MECÁNICA
NOMBRE | APELLIDOS | CÓDIGO | ROL EN EL PROYECTO
SOFIA SALOMÉ | ESPITIA JIMENEZ | 1080046389 | DISEÑADORA
NOMBRE | APELLIDOS | CÓDIGO | ROL EN EL PROYECTO
JULIÁN ANDRÉS | GARCIA | 1088004478 | ELECTRÓNICO
NOMBRE | APELLIDOS | CÓDIGO | ROL EN EL PROYECTO
JOSE LISANDER | HURTADO | 1088028747 | PROGRAMADOR

### FECHA DE ENTREGA (DD/MM/AA): 03/04/2026

### SEMANA NO: 10 Y 11 RESPONSABLE DEL REGISTRO: Jose Lisander Hurtado

### ETAPA/FASE DEL PROYECTO: Diseño de mecanismo cargar y descarga, prueba de sensores y

verificación en pista, autonomía básica.

### PLANEACIÓN

### OBJETIVOS (Definidos en la reunión de planeación):

1. Enviar a fabricar PCB a China.
2. Integración de sensores y verificación por medio de protoboard.
3. Diseñar mecanismo de carga y descarga.

### 4. Organizar y actualizar la documentación técnica (bitácora)

5. Autonomía básica, seguimiento de línea y detección frente a un obstáculo.
ACTIVIDAD | FECHA DE INICIO | FECHA FINAL | MATERIALES | PRESUPUE STO | RIESGOS POTENCIALES | ALTERNATIVAS | ENTREGABLE | RESPONSABLE
Envío a fabricación de PCB | 6-4-202 6 | 6-04-20 26 | Página de fabricante de PCB en China. | $60.000 | Solicitud de fabricación rechazada por archivos no compatible s. | Seguimiento a la solicitud, verificación de correo de confirmación | Número de solicitud de fabricación. | Sofia.

SEMESTRE INTEGRADOR | CÓDIGO | FI-F-001
BITÁCORA | VERSIÓN | 2
ACTIVIDAD | FECHA DE INICIO | FECHA FINAL | MATERIALES | PRESUPUE STO | RIESGOS POTENCIALES | ALTERNATIVAS | ENTREGABLE | RESPONSABLE
Ubicación definitiva de componentes eléctricos y electrónicos en robot | 07-04-2 026 | 07-04-2 026 | Sensores, reguladores de voltaje, esp32, raspberry pi 5, driver | $ 219.672 | Distribució n irregular que genere recalentami ento en component es | Solicitar recomendacio nes de distribución a los profesores guías. | Archivo esquemático con componente s definitivos. | Sofia
Conexión de sensores a la protoboard | 6-4-202 6 | 6-4-2026 | Sensores | $ 219.672 | Malas conexiones de sensores y funcionami ento irregular de los mismos. | Probar con otra referencia de sensores en caso de que los seleccionados no funciones correctamente | Sensores funcionando con protoboard. | Julián.
Integración de sensores al chasis. | 7-4-2026 | 8-4-202 6 | Sensores | $ 439.344 | Dificultad para integrar los sensores al chasis | Hacer un ensamblaje en fusión | Sensores integrados al chasis del robot | Julián.
Programación de sensores con Raspberry pi 5. | 9-4-202 6 | 10-4-20 26 | Computador, robot prototipo, Raspberry pi 5 | $ 439344 | Indicacione s incorrectas de los sensores | Cambio en la programación inicial. | Sensores funcionando correctamen te en Robot | José.
Pruebas en pista para la verificación de los sensores. | 10-4-20 26 | 10-4-20 26 | Computador, robot prototipo, Raspberry pi 5 | $ 219.672 | Los sensores no reconocen las señales de la pista. | Calibración de sensores, cambio en la programación. | Robot prototipo con integración correcta de sensores | José.
Programación para que el robot siga una línea y se detenga frente a un obstáculo | 12/4/2 026 | 15/4/2 026 | Computador, Raspberry, Sensores. | $878.688 | Que el robot no siga líneas y no se detenga frente a un obstáculo | Cambio en la programación, calibración y ajuste de sensores | Robot con seguimiento de línea y detección frente a un obstáculo. | José
Diseño de mecanismo carga y descarga | 9-04-20 26 | 10-03-2 026 | Software CAD, computador | $ 439.344 | Error de diseño y acople incorrectos | Buscar alternativas existentes en internet. | Diseño CAD completo | Vanesa

SEMESTRE INTEGRADOR | CÓDIGO | FI-F-001
BITÁCORA | VERSIÓN | 2
ACTIVIDAD | FECHA DE INICIO | FECHA FINAL | MATERIALES | PRESUPUE STO | RIESGOS POTENCIALES | ALTERNATIVAS | ENTREGABLE | RESPONSABLE
Fabricación de piezas mecanismo de carga y descarga | 12/4/2 2026 | 13/4/2 026 | Impresora 3D, rodamientos, tornillos. | $50.000 | Impresione s con defectos, dificultad en conseguir materiales requeridos | Cambiar parámetros de impresión. | Piezas listas para ensamblar en robot | Vanesa.
Ensamblaje mecanismo de carga y descarga en robot | 14/4/2 026 | 15/4/2 026 | Tornillos, tuercas, arandelas. | $439.344 | Funcionami ento irregular del mecanismo ensamblad o en robot | Cambiar las piezas que no funcionen correctamente , apoyarnos en diseños existentes. | Robot con mecanismo de carga y descarga | Vanesa.
Matriz de control de cambios y riesgos | 16/4/2 026 | 17/4/2 026 | Computador | $219.672 | Documento con faltante de informació n | Consultar al profesor guía. | Documento matriz de cambios y riesgos | Sofia.
Repositorio de código para control de motores | 15/4/2 026 | 16/4/2 026 | Computador | $219.672 | Código de programaci ón que no funcione correctame nte con motores | | | Vanesa
Bitácora 5 Programación semana 12 y 13 | 17/4/2 026 | 17/4/2 026 | Computador, Google Docs | $ 219.672 | Inconsisten cias en informació n | Validación con el equipo | Bitácora de la semana 10 y 11 | Julián

SEMESTRE INTEGRADOR | CÓDIGO | FI-F-001
BITÁCORA | VERSIÓN | 2

### EJECUCIÓN

ACTIVIDAD | FECHA INICIO | FECHA FIN | OPORTUNIDADES DE MEJORA O DESAFÍOS ENCONTRADOS | ACCIONES CORRECTIVAS O DE MEJORA | ESTADO DE ENTREGABLE | RESPONSABLE
Envío a fabricación de PCB | 6-4-2026 | 6-4-2026 | Durante la revisión se encontró que algunas borneras no funcionan con el calibre de cable a utilizar. | Se realizó el cambio correspondiente a los conectores de la librería con-wago 500 | Completado | Sofia
Ubicación definitiva de componentes eléctricos y electrónicos en robot | 07-04-2026 | 07-04-2026 | Dificultad para ubicar la raspberry de manera que el cable flex de la cámara no quedara con ningún quiebre que afectará el funcionamiento. | Buscando la mejor ubicación de componentes se realizaron varios ensamblajes en fusion. | Completado | Sofia.
Conexión de sensores a la protoboard | 6-4-2026 | 6-4- 2026 | Se presentó confusión al momento de conectar el sensor de ultrasonido por el voltaje de alimentación | Se realizó varias consultas y finalmente se conectó el sensor a 5V, funcionando correctamente | Parcial, ya que no se conectaron el resto de sensores | Julián
Integración de sensores al chasis. | 7-4- 2026 | 8-4-2026 | El diseño 3D no encajaba con facilidad en el sensor de ultrasonido | Se amplió el tamaño de las perforaciones para facilitar el ensamble. | Parcial | Julián
Programación de sensores con Raspberry pi 5. | 9-4-2026 | 10-4-2026 | El código de programación inicialmente no funcionó, ya que tenían parámetros incorrectos. | Al solicitar ayuda al profesor, él nos suministra el código correcto. | Completado | Jose.
Pruebas en pista para la verificación de los sensores. | 10-4-2026 | 10-4-2026 | Ninguna | Ninguna | Completado | Jose.
Programación para que el | 12/4/2026 | 15/4/2026 | El robot se detiene frente a un obstáculo gracias al | Seguir con las pruebas en pista para mejorar el | Parcial | Jose.

SEMESTRE INTEGRADOR | CÓDIGO | FI-F-001
BITÁCORA | VERSIÓN | 2
robot siga una línea y se detenga frente a un obstáculo | | | sensor de ultrasonido, sin embargo no logra corregir la trayectoria por medio del ackermann. | código de programación logrando que el robot se desplace en línea recta corrigiendo trayectorias.
Diseño de mecanismo carga y descarga | 9-04-2026 | 10-03-2026 | El equipo encargado de pista realizará la labor del mecanismos de carga y descarga | Ninguno | Completado | Vanesa.
Fabricación de piezas mecanismo de carga y descarga | 12/4/22026 | 13/4/2026 | El equipo encargado de pista realizará la labor del mecanismos de carga y descarga | Ninguno | Completado | Vanesa.
Ensamblaje mecanismo de carga y descarga en robot | 14/4/2026 | 15/4/2026 | El equipo encargado de pista realizará la labor del mecanismos de carga y descarga | Ninguno | Completado | Vanesa.
Matriz de control de cambios y riesgos | 16/4/2026 | 17/4/2026 | Ninguno | Ninguno | Completado | Vanesa
Repositorio de código para control de motores | 15/4/2026 | 16/4/2026 | Dificultad para que los motores regulen la velocidad, es decir que ambos motores giren a la misma velocidad. | Por medio de las pruebas realizadas, se mejora el código de programación, para que el robot se mueva en línea recta. | Completado | Vanesa
Bitácora 5 Programación semana 12 y 13 | 17/4/2026 | 17/4/2026 | Ninguno | Ninguno | Completado | Julián

SEMESTRE INTEGRADOR | CÓDIGO | FI-F-001
BITÁCORA | VERSIÓN | 2

### ANÁLISIS DE CAUSA RAÍZ DESAFÍOS ENCONTRADOS:

### EVIDENCIA (FOTOGRAFÍA Y ENLACE A REPOSITORIO):

### PCB,s

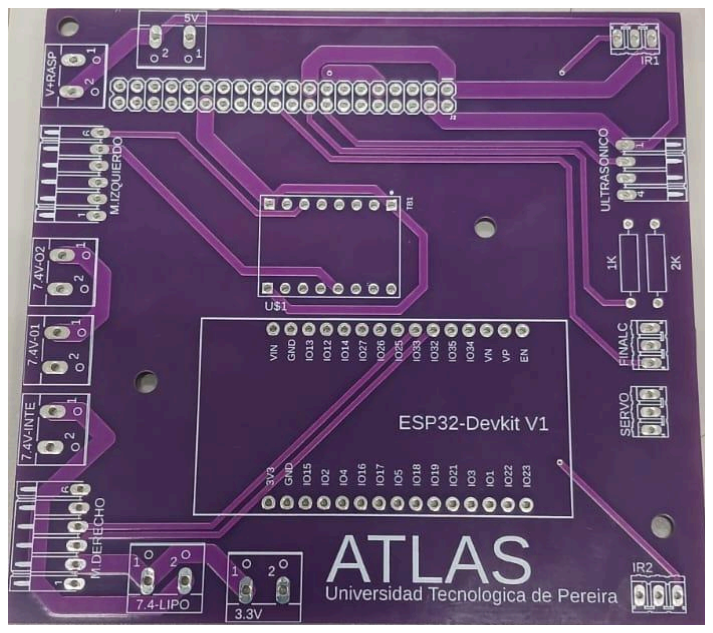
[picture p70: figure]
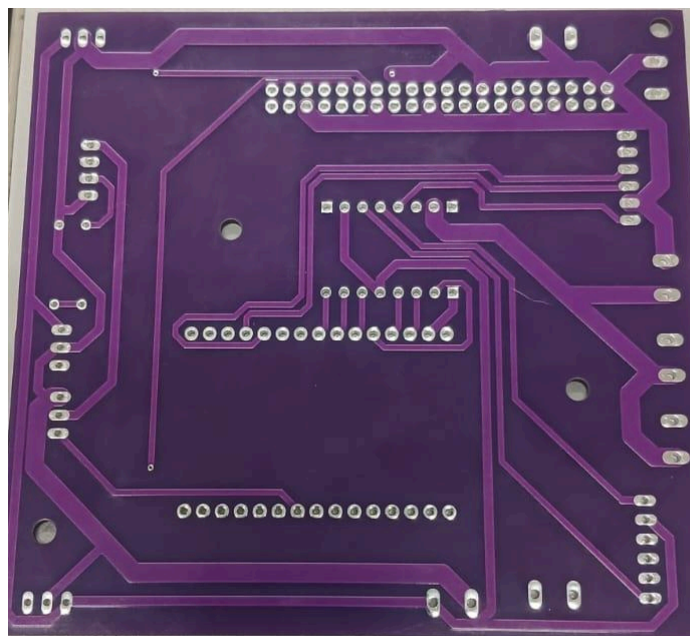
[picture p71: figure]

Ubicación de componentes.

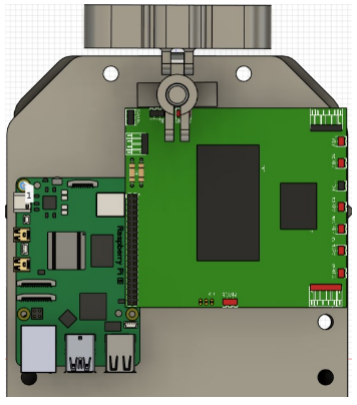
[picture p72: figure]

SEMESTRE INTEGRADOR | CÓDIGO | FI-F-001
BITÁCORA | VERSIÓN | 2

Integración sensor de ultrasonido.

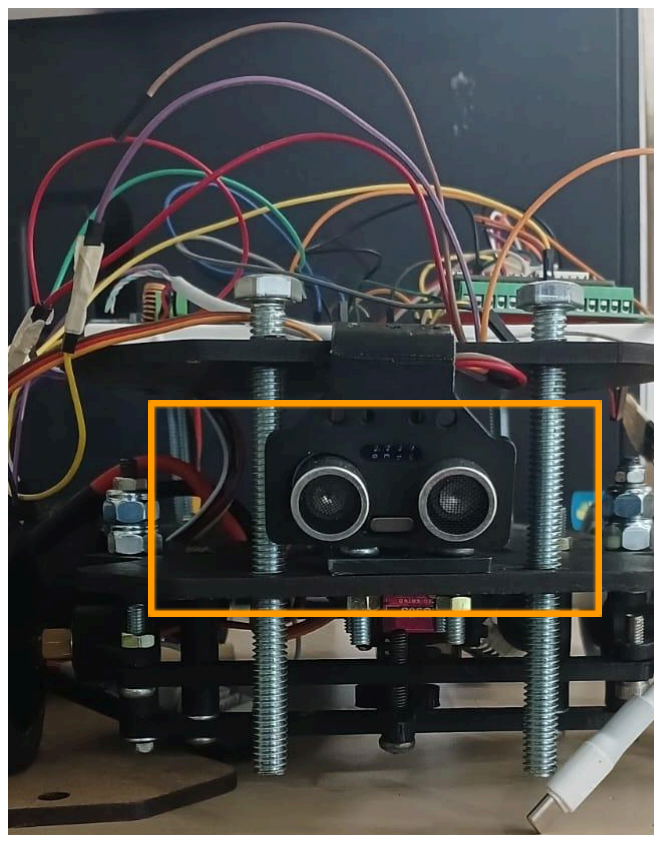
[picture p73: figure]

Robot deteniéndose frente a un obstáculo.

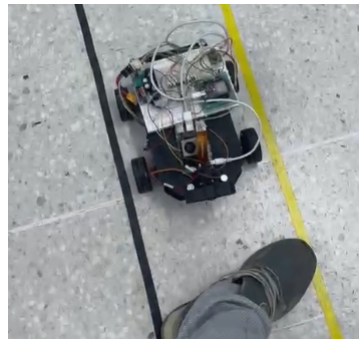
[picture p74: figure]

SEMESTRE INTEGRADOR | CÓDIGO | FI-F-001
BITÁCORA | VERSIÓN | 2

Listado maestro de documentos.

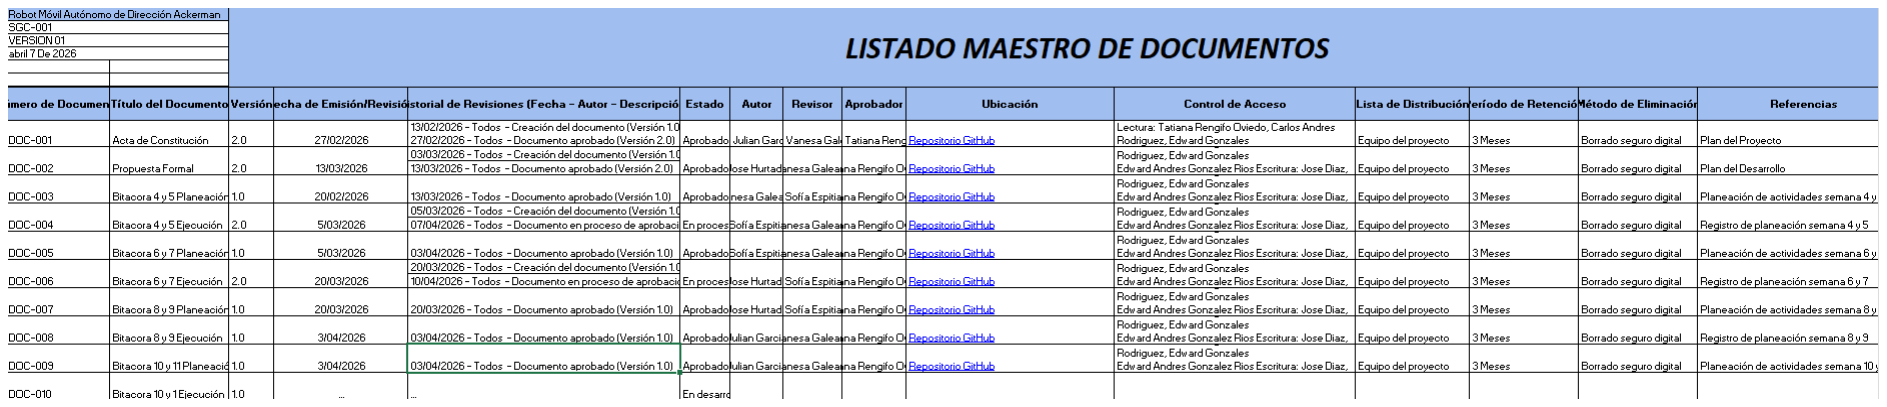
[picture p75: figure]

MATERIALES | CANT. | UNIDAD DE MEDIDA | COSTO UNITARIO SIN IVA | IVA | COSTO TOTAL | JUSTIFICACIÓN
PCB | 5 | UNIDAD | 35.640 | 8360 | 44000 | Requerimiento del proyecto, fabricación de PCB en China.
COMPROMISOS | RESPONSABLE

### FECHA DE INICIO

### FECHA FIN

### APRENDIZAJES CLAVE

### OBSERVACIONES DOCENTES

OBSERVACIÓN | FECHA | DOCENTE

SEMESTRE INTEGRADOR | CÓDIGO | FI-F-001
BITÁCORA | VERSIÓN | 2

### CONTROL DE CAMBIOS ESPACIO SOLO PARA CAMBIOS DEL FORMATO

RESPONSABLE DEL CAMBIO | JUSTIFICACIÓN DEL CAMBIO | DESCRIPCIÓN DEL CAMBIO | FECHA DE CAMBIO | NÚMERO DEL CAMBIO
Angie Tatiana Rengifo Oviedo | Se encontró que el formato anterior le faltaba información y era confuso para el proceso de ABP | Modificación de parámetros en la documentación de la ejecución. | 30/01/2026 | Versión 2

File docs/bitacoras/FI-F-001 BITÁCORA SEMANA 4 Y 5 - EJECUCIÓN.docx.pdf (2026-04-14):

### INGENIERÍA MECATRÓNICA

SEMESTRE INTEGRADOR | CÓDIGO | FI-F-001
BITÁCORA | VERSIÓN | 2

IDENTIFICACIÓN DEL PROYECTO

NOMBRE DEL PROYECTO: ATLAS

INTEGRANTES DEL EQUIPO
NOMBRE | APELLIDOS | CÓDIGO | ROL EN EL PROYECTO
VANESA | GALEANO FRANCO | 1109292401 | PROGRAMADORA
NOMBRE | APELLIDOS | CÓDIGO | ROL EN EL PROYECTO
SOFIA SALOMÉ | ESPITIA JIMENEZ | 1080046389 | DISEÑADORA
NOMBRE | APELLIDOS | CÓDIGO | ROL EN EL PROYECTO
JULIÁN ANDRÉS | GARCIA | 1088004478 | ELECTRÓNICO
NOMBRE | APELLIDOS | CÓDIGO | ROL EN EL PROYECTO
JOSE LISANDER | HURTADO | 1088028747 | MECÁNICO

FECHA DE ENTREGA (DD/MM/AA): 03/02/2026

SEMANA NO: 4 y 5
RESPONSABLE DEL REGISTRO: Sofía Salomé Espitia Jiménez

ETAPA/FASE DEL PROYECTO:Modelado CAD

PLANEACIÓN

OBJETIVOS (Definidos en la reunión de planeación):
1. Diseñar el sistema mecánico del robot (Ackerman, chasis y distribución de componentes en CAD).
2. Fabricar y validar piezas como soportes y acoples mediante impresión 3D y ajustes de diseño.
3. Organizar y actualizar la documentación técnica (bitácora y listado de materiales).
ACTIVIDAD | FECHA DE INICIO | FECHA FINAL | MATERIALES | PRESUPUESTO | RIESGOS POTENCIALES | ALTERNATIVAS | ENTREGABLE | RESPONSABLE
Diseño sistema Ackerman | 23-2-2 6 | 27-2-2 6 | Software CAD, computado r | $ 0 | Error en geometría de giro, mala alineación | Ajuste de parámetros en CAD, simulación previa | Modelo CAD del sistema Ackerman | Sofía

SEMESTRE INTEGRADOR | CÓDIGO | FI-F-001
BITÁCORA | VERSIÓN | 2
ACTIVIDAD | FECHA DE INICIO | FECHA FINAL | MATERIALES | PRESUPUESTO | RIESGOS POTENCIALES | ALTERNATIVAS | ENTREGABLE | RESPONSABLE
Impresión 3D de soportes de motores | 24-2-2 6 | 26-2-2 6 | Impresora 3D, filamento PLA, motores | $ 0 | Fallas de impresión, medidas incorrectas | Reimpresión, ajuste de tolerancias | Soportes impresos | Julián
Impresión 3D de acoples de ruedas | 24-2-2 6 | 26-2-2 6 | Impresora 3D, filamento, ruedas | $ 0 | Desajuste con eje del motor | Rediseño del acople | Acoples funcionales impresos | Julián
Adelantar documentación semana 5 | 26-2-2 6 | 28-2-2 6 | Computad or, formato de APA | $ 0 | Informació n incompleta | Revisión con el equipo | Documento adelantado | Jose
Diseño de chasis | 23-2-2 6 | 3-3-26 | Software CAD | $ 0 | Interferenci as entre component es | Ajustes estructurales en CAD | Modelo CAD del chasis | Vanesa
Ubicación detallada de componentes (CAD) | 2-3-26 | 4-3-26 | Software CAD, fichas técnicas | $ 0 | Mala distribució n de peso | Reubicación estratégica | Ensamble digital completo | Jose
Tabla en Excel listado de materiales | 3-3-26 | 4-3-26 | Computad or, Excel | $ 0 | Omisión de materiales | Revisión cruzada con diseño CAD | Lista de materiales | Sofía
Bitácora 2 | 4-3-26 | 6-3-26 | Computad or, software CAD | $ 0 | Inconsisten cias en informació n | Validación con el equipo | Bitácora 2 y modelo conceptual | Vanesa
Recopilación para la tarea Classroom: modelado CAD conceptual | 2-3-26 | 6-3-26 | Computad or | $ 0 | Inconsisten cias en informació n | Validación con el equipo | Documento en apa completo | Julian

EJECUCIÓN

SEMESTRE INTEGRADOR | CÓDIGO | FI-F-001
BITÁCORA | VERSIÓN | 2
ACTIVIDAD | FECHA INICIO | FECHA FIN | OPORTUNIDADES DE MEJORA O DESAFÍOS ENCONTRADOS | ACCIONES CORRECTIVAS O DE MEJORA | ESTADO DE ENTREGABLE | RESPONSABLE
Impresión 3D de soportes de motores | 24-2-26 | 25-2-26 | Tiempo de impresión, calidad de la pieza | Tolerancias de impresión | Completado | Julián
Impresión 3D de acoples de ruedas | 24-2-26 | 25-2-26 | Tiempo de impresión, calidad de la pieza | Tolerancias de impresión | Completado | Julián
Adelantar documentació n semana 5 | 26-2-26 | 28-2-26 | Cumplir con las sugerencias, actualizar el documento constantemente | Redacción, estructuración del documento | Completado | Jose
Diseño de chasis | 23-2-26 | 3-3-26 | Estandarización de tornillería, definir el material | Diseño paso a paso, ensambles para verificar | Completado | Vanesa
Ubicación detallada de componentes (CAD) | 2-3-26 | 4-3-26 | Encontrar referencias exactas, escalar modelos | Acoples, restricciones de movimiento | En proceso | Jose
Tabla en Excel listado de materiales | 3-3-26 | 4-3-26 | Encontrar referencias exactas, encontrar los datasheets correspondientes | Organización del documento, información suministrada | Falta | Sofía
Bitácora 2 | 4-3-26 | 6-3-26 | Cumplir con las sugerencias, actualizar el documento constantemente | Redacción, estructuración del documento, planeamiento del presupuesto | En proceso | Vanesa
Recopilación para la tarea Classroom: modelado CAD conceptual | 2-3-26 | 6-3-26 | Organización en la ubicación de archivos, clasificación por carpetas | Delegación de responsabilidade s | Completado | Julian

ANÁLISIS DE CAUSA RAÍZ DESAFÍOS ENCONTRADOS:

Durante la etapa de fabricación mediante impresión 3D, se evidenciaron desviaciones dimensionales en las piezas, particularmente en los acoples mecánicos, lo que generó dificultades en el ensamblaje y retrabajos. A partir de un análisis de causa–raíz, se identificó que el problema no radica únicamente en la ejecución del proceso de impresión, sino principalmente en la ausencia de tolerancias mecánicas definidas desde la etapa de diseño CAD.

SEMESTRE INTEGRADOR | CÓDIGO | FI-F-001
BITÁCORA | VERSIÓN | 2

Adicionalmente, se reconoce la influencia de factores propios del proceso de manufactura aditiva, como la contracción del material PLA, la precisión de la impresora y la variabilidad en parámetros de impresión (temperatura, velocidad y flujo), los cuales no fueron previamente estandarizados ni validados mediante prototipos de prueba. Esta combinación de factores derivó en piezas que, aunque geométricamente correctas en el modelo digital, no cumplen con los requerimientos funcionales en el ensamble físico.

EVIDENCIA (FOTOGRAFÍA Y ENLACE A REPOSITORIO):

Link: https://github.com/Espitiass/G7ACKER.git

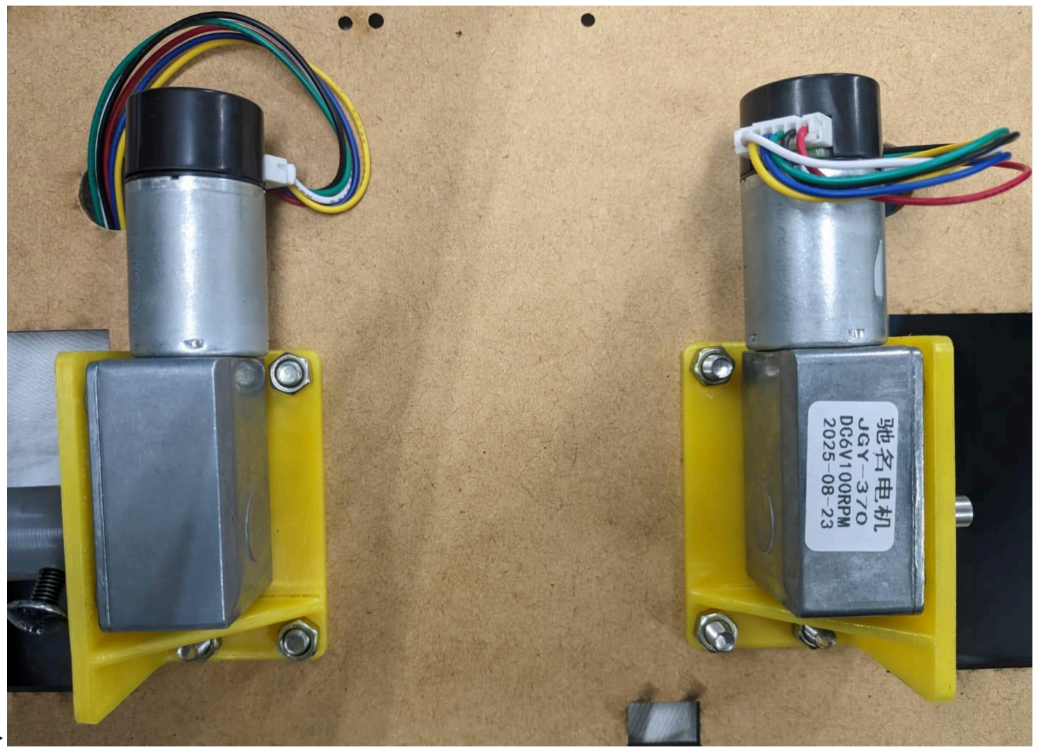
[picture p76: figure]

→

SEMESTRE INTEGRADOR | CÓDIGO | FI-F-001
BITÁCORA | VERSIÓN | 2

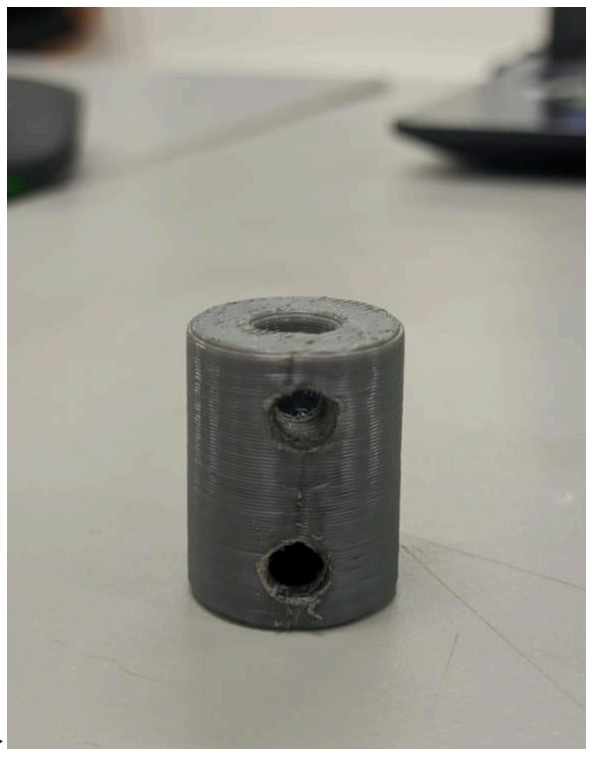
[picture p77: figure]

→

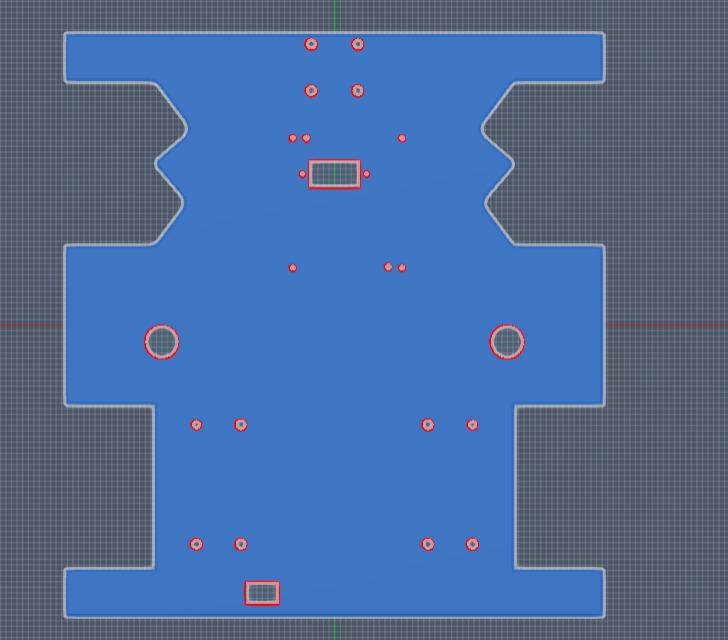
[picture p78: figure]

→

SEMESTRE INTEGRADOR | CÓDIGO | FI-F-001
BITÁCORA | VERSIÓN | 2

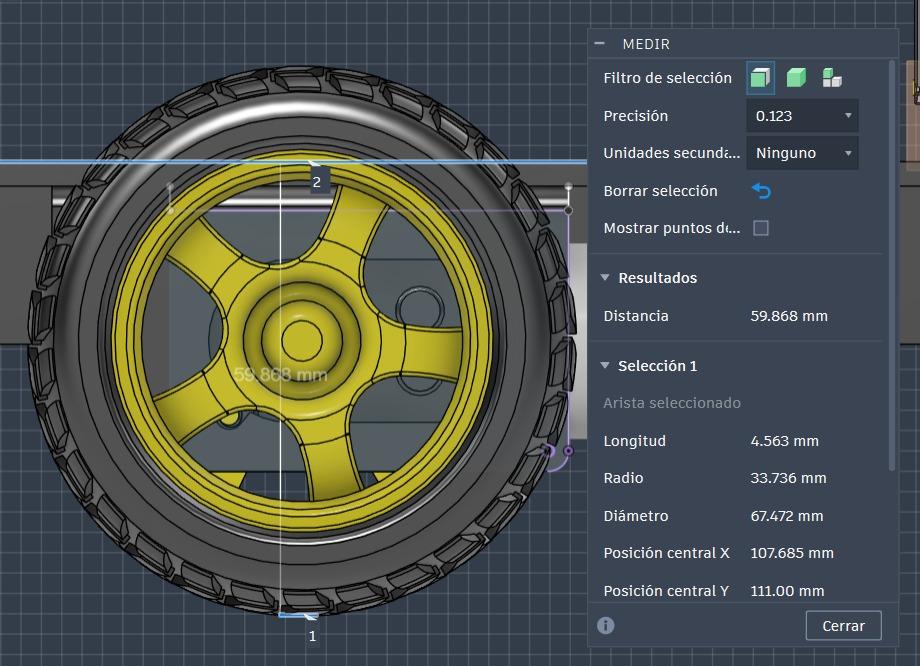
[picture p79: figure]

→

MATERIALES AÑADIDOS | CANT . | UNIDAD DE MEDIDA | COSTO UNITARIO SIN IVA | IVA | COSTO TOTAL | JUSTIFICACIÓN
Rodamientos 605RS | 4 | 5 mm de diámetro | $ 4.050 | $950 | $20.000 | Se necesitaba probar el mecanismo ackerman
Tornillos M4*20 | 10 | 4*20 mm | $ 121.5 | $285 | $1.500 | Necesarios para ensamblar el chasis y ackerman
Tuercas Hex 4-0.7 | 10 | 4-0.7 mm | $ 40.5 | $ 95 | $500 | Necesarios para ensamblar el chasis y ackerman
Tornillos M5*20 | 10 | 4*20 mm | $ 145.8 | $ 342 | $1.800 | Necesarios para ensamblar el chasis y ackerman
Tuercas Hex 5-0.8 | 10 | 5-0.8 mm | $ 40.5 | $ 95 | $500 | Necesarios para ensamblar el chasis y ackerman
Tornillos M3*20 | 10 | 3*20 mm | $ 78.48 | $ 15.2 | $800 | Necesarios para ensamblar el chasis y ackerman

SEMESTRE INTEGRADOR | CÓDIGO | FI-F-001
BITÁCORA | VERSIÓN | 2
Tuercas Hex 3-0.5 | 10 | 3-0.5 mm | $ 78.48 | $15.2 | $800 | Necesarios para ensamblar el chasis y ackerman
Tornillo M5*10 | 8 | 5*10 mm | $ 263.25 | $494 | $2600 | Necesarios para ensamblar el chasis y ackerman
Tornillo M5*16 | 4 | 5*16 mm | $ 263.25 | $247 | $1300 | Necesarios para ensamblar el chasis y ackerman
Tuerca Zinc 5 | 10 | 5 mm de diámetro | $ 56.7 | $133 | $700 | Necesarios para ensamblar el chasis y ackerman
COMPROMISOS | RESPONSABLE | FECHA DE INICIO | FECHA FIN | APRENDIZAJES CLAVE
Rediseñar las piezas mecánicas incorporando tolerancias de fabricación adecuadas para garantizar un correcto ensamble. Además, realizar pruebas de validación mediante prototipos impresos y definir parámetros de impresión estandarizados que aseguren la calidad y repetibilidad del proceso. | Vanesa | 04-03-2026 | 06-03-2026 | Comprensión de la importancia de las tolerancias mecánicas en diseño para manufactura (DFM) y su impacto en la precisión y funcionalidad de sistemas ensamblados mediante impresión 3D.

OBSERVACIONES DOCENTES

OBSERVACIÓN | FECHA | DOCENTE

SEMESTRE INTEGRADOR | CÓDIGO | FI-F-001
BITÁCORA | VERSIÓN | 2

CONTROL DE CAMBIOS
ESPACIO SOLO PARA CAMBIOS DEL FORMATO
RESPONSABLE DEL CAMBIO | JUSTIFICACIÓN DEL CAMBIO | DESCRIPCIÓN DEL CAMBIO | FECHA DE CAMBIO | NÚMERO DEL CAMBIO
Angie Tatiana Rengifo Oviedo | Se encontró que el formato anterior le faltaba información y era confuso para el proceso de ABP | Modificación de parámetros en la documentación de la ejecución. | 30/01/2026 | Versión 2

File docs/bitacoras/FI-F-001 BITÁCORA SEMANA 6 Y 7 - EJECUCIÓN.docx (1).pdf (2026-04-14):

### IDENTIFICACIÓN DEL PROYECTO

### NOMBRE DEL PROYECTO: ATLAS

### INTEGRANTES DEL EQUIPO

NOMBRE | APELLIDOS | CÓDIGO | ROL EN EL PROYECTO
VANESA | GALEANO FRANCO | 1109292401 | PROGRAMADORA
NOMBRE | APELLIDOS | CÓDIGO | ROL EN EL PROYECTO
SOFIA SALOMÉ | ESPITIA JIMENEZ | 1080046389 | ELECTRÓNICO
NOMBRE | APELLIDOS | CÓDIGO | ROL EN EL PROYECTO
JULIÁN ANDRÉS | GARCIA | 1088004478 | DISEÑADOR
NOMBRE | APELLIDOS | CÓDIGO | ROL EN EL PROYECTO
JOSE LISANDER | HURTADO | 1088028747 | MECÁNICO

### FECHA DE ENTREGA (DD/MM/AA): 03/02/2026

### SEMANA NO: 6 Y 7 RESPONSABLE DEL REGISTRO: Sofía Salomé Espitia Jiménez

### ETAPA/FASE DEL PROYECTO: Pruebas y Electrónica

### PLANEACIÓN

### OBJETIVOS (Definidos en la reunión de planeación):

1. Validar el sistema de tracción y dirección del robot en un circuito de pruebas secuenciales.
2. Diseñar la tarjeta electrónica garantizando conexiones estables, distribución de voltaje adecuada y los tamaños óptimos.

### 3. Programar el sistema de visión utilizando la cámara IMX219 para la detección de

elementos.
4. Actualizar la documentación técnica del proyecto asegurando coherencia y trazabilidad de los avances.
ACTIVIDAD | FECHA DE INICIO | FECHA FINAL | MATERIALES | PRESUPUESTO | RIESGOS POTENCIALES | ALTERNATIVAS | ENTREGABLE | RESPONSABLE
Prueba de motores | 09-03-2016 | 10-03-2016 | Motores, ruedas, driver, protoboard , jumpers, | $ 0 | Posible corto en el circuito desarrollad o | Verificar todo el circuito antes de alimentarlo | Circuito funcional con la ejecución correcta de los motores | Julián

## INGENIERÍA MECATRÓNICA

SEMESTRE INTEGRADOR | CÓDIGO | FI-F-001
BITÁCORA | VERSIÓN | 2

ACTIVIDAD | FECHA DE INICIO | FECHA FINAL | MATERIALES | PRESUPUESTO | RIESGOS POTENCIALES | ALTERNATIVAS | ENTREGABLE | RESPONSABLE
| | | fuente de voltaje
Validación de dirección y tracción | 10-03-2026 | 11-03-2026 | Chasis, dirección ackerman, sistema de tracción | $ 0 | Fallos al momento de giro o propulsión | Verificar los ángulos de giro permitidos y la alimentación de motores | Chasis de robot móvil y controlable | Julián
Diseño de mecanismo carga y descarga | 09-03-2026 | 10-03-2026 | Software CAD, computado r | $ 0 | Error de diseño y acople incorrectos | Ensamble las piezas a realizar | Diseño CAD completo | Sofía
Fabricación y ensamblaje de componentes | 10-03-2026 | 11-03-2026 | Herramient as, destornilla dores, prensa, tornillería | $ 0 | Acople inadecuado s entre piezas o de difícil acceso | Rediseñar pieza o realizar modificacion es en físico. | Sistema de carga y descarga físico | Sofía
Corte láser de chasis e impresión. | 09-03-2026 | 10-03-2026 | Impresora 3D, filamento, Cortadora laser, MDF, acrílico | $ 0 | Factores de tolerancia que dificulten el ensamble mecánico | Conocer la tolerancia de las máquinas a utilizar y modificar las medidas de los diseños | Estructura física del sistema de carga y descarga | Vanesa
Adquisición de materiales. | 10-03-2026 | 11-03-2026 | Reguladore s de voltaje, cables de conexión, ESP32, puertos USB-C | $80.000 | No encontrar la referencia exacta, elementos fuera del presupuest o | Vulgar alternativas comerciales a los materiales base | Materiales comprados | Vanesa
Ensamble mecánico. | 12-03-2026 | 15-03-2026 | Herramient as, destornilla dores, prensa, tornillería | $ 0 | Acople inadecuado s entre piezas o de difícil acceso | Rediseñar pieza o realizar modificacion es en físico. | Estructura interna del robot | Jose
SEMESTRE INTEGRADOR | CÓDIGO | FI-F-001
BITÁCORA | VERSIÓN | 2

ACTIVIDAD | FECHA DE INICIO | FECHA FINAL | MATERIALES | PRESUPUESTO | RIESGOS POTENCIALES | ALTERNATIVAS | ENTREGABLE | RESPONSABLE
Ajustes y refuerzos | 15-03-2026 | 17-03-2026 | Herramient as, destornilla dores, prensa, tornillería, pie de rey | $ 0 | Errores de diseños que limiten las capacidade s del robot o las anulen | Rediseño de la estructura o realizar cambios en físico | Estructura interna del robot funcional | Todos
Diseño electrónico (Tarjeta electrónica) | 17-03-2026 | 19-03-2026 | Software EDA, computado r, circuito en protoboard funcional | $ 0 | Medida incorrecta o ruta poco funcionales para el circuito | Conocer y tener claro las dimesion posibles y los métodos adecuados para el desarrollo | Diseño electrónico completo | Vanesa
Programación Raspberry Pi 5 | 19-03-2026 | 20-03-2026 | Entorno de programaci ón (Python), Raspberry Pi 5, librerías OpenCV, GPIO y comunicaci ón serial | $ 0 | Bugs dentro del código, problemas en la conexión con la raspberry | Entender el protocolo de comunicació n y las librerías necesarias para este | Código de Visión | Vanesa
Chasis armado versión preliminar | 19-03-2026 | 20-03-2026 | Herramient as, destornilla dores, prensa, tornillería | $ 0 | Acople inadecuado s entre piezas o de difícil acceso | Rediseñar piezas o realizar modificacion es en físico | Versión preliminar del chasís en físico | Jose
Informe de avance y lecciones aprendidas | 19-03-1016 | 20-03-2026 | Computad or, Google Docs | $ 0 | Inconsisten cias en informació n | Validación con el equipo | Informe completo | Julián
Bitácora 3 Programación semana 8 y 9 | 19-03-2026 | 20-03-2026 | Computad or, Google Docs | $ 0 | Inconsisten cias en informació n | Validación con el equipo | Bitácora de la semana 8 y 9 | Julián
SEMESTRE INTEGRADOR | CÓDIGO | FI-F-001
BITÁCORA | VERSIÓN | 2

### EJECUCIÓN

ACTIVIDAD | FECHA INICIO | FECHA FIN | OPORTUNIDADES DE MEJORA O DESAFÍOS ENCONTRADOS | ACCIONES CORRECTIVAS O DE MEJORA | ESTADO DE ENTREGABLE | RESPONSABL E
Prueba de motores | 09-03-2026 | 10-03-2016 | Se identificaron picos de corriente elevados al momento del arranque de los motores, afectando la estabilidad del sistema. | Se implementó el uso de un driver de motores (TB6612) para regular la entrega de corriente, permitiendo un arranque progresivo y protegiendo los componentes electrónicos. | Completado | Julian
Validación de dirección y tracción | 10-03-2026 | 11-03-2026 | Baja precisión en las piezas impresas, afectando la geometría del sistema de dirección Ackerman. | Se optó por realizar las impresiones en un equipo con mejor calibración, garantizando mayor precisión dimensional y correcto funcionamiento del sistema de dirección. | Completado | Julian
Diseño de mecanismo carga y descarga | 09-03-2026 | N/A | La actividad no se ejecutó según lo planificado, generando retrasos en el cronograma. | Se reprogramó la actividad priorizando su desarrollo en la siguiente iteración, ajustando la planificación del equipo. | Incompleto
Fabricación y ensamblaje de componentes | 10-03-2026 | 11-03-2026 | Desalineación en el acople entre el motor y los componentes mecánicos, generando riesgo de fallo estructural. | Se rediseñaron puntos de fijación y se incorporaron perforaciones estratégicas para mejorar la sujeción y alineación del sistema. | Completado | Sofia
Corte láser de chasis e impresión. | 09-03-2026 | 10-03-2026 | El uso de MDF generó posibles aflojamientos debido a vibraciones mecánicas. | Se incorporaron arandelas para distribuir la carga y evitar el deterioro del material, mejorando la fijación de los tornillos. | Completado | Vanesa
Adquisición de materiales. | 10-03-2026 | 11-03-2026 | Posible falta de componentes | Se realizó verificación previa de requerimientos y se | Completado | Vanesa
SEMESTRE INTEGRADOR | CÓDIGO | FI-F-001
BITÁCORA | VERSIÓN | 2

| | | electrónicos durante el ensamblaje. | definieron alternativas comerciales equivalentes para asegurar disponibilidad.
Ensamble mecánico. | 12-03-2026 | 15-03-2026 | Incompatibilidades dimensionales en piezas impresas que dificultaron el ensamblaje. | Se realizaron ajustes controlados en las piezas y se plantea la incorporación de tolerancias en el rediseño para evitar retrabajos. | Completado | Jose
Ajustes y refuerzos | 15-03-2026 | 17-03-2026 | No se identificaron problemas críticos durante esta etapa. | Se mantuvo el diseño y se reforzaron puntos estructurales para mejorar la estabilidad general del sistema. | Completado | Todos
Diseño electrónico (Tarjeta electrónica) | 17-03-2026 | 19-03-2026 | Dificultades en la distribución de componentes y rutas del circuito. | Se revisaron las dimensiones del diseño y se optimizó la disposición de pistas para mejorar funcionalidad y fabricación. | Incompleto | vanesa
Programación Raspberry Pi 5 | 19-03-2026 | 20-03-2026 | Errores en la ejecución del código y fallos en el control de los motores. | Se implementaron librerías como OpenCV, GPIO y serial para el procesamiento de imagen, control y comunicación del sistema, realizando ajustes en el código para garantizar movimientos correctos del robot. | Completado | Vanesa
Chasis armado versión preliminar | 19-03-2026 | 20-03-2026 | Desalineación del servomotor respecto al eje de giro del sistema de dirección. | Se ajustó la geometría del acople modificando la posición del orificio para lograr alineación con el punto de giro. | Completado | Jose
Informe de avance y lecciones aprendidas | 19-03-2026 | 20-03-2026 | Identificación de múltiples fallos en acoples y fabricación. | Se documentaron las fallas y se plantearon mejoras en diseño y fabricación para siguientes iteraciones. | Completado | Julian
SEMESTRE INTEGRADOR | CÓDIGO | FI-F-001
BITÁCORA | VERSIÓN | 2

Bitácora 3
Programación
semana 8 y 9
19-03-2026 | 20-03-2026 | Tareas incompletas dentro del tiempo establecido.

Se reorganizó la
planificación del
equipo para asegurar
el cumplimiento de
actividades en
próximas semanas.
Completado | Julian

### ANÁLISIS DE CAUSA RAÍZ DESAFÍOS ENCONTRADOS:

### EVIDENCIA (FOTOGRAFÍA Y ENLACE A REPOSITORIO):

SEMESTRE INTEGRADOR | CÓDIGO | FI-F-001
BITÁCORA | VERSIÓN | 2

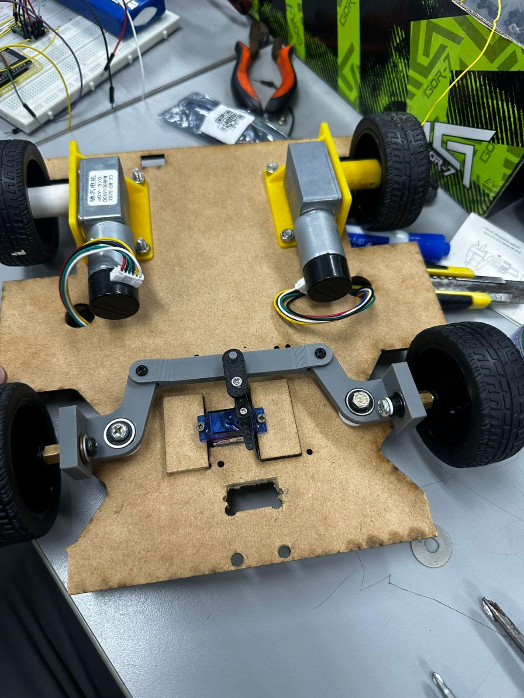
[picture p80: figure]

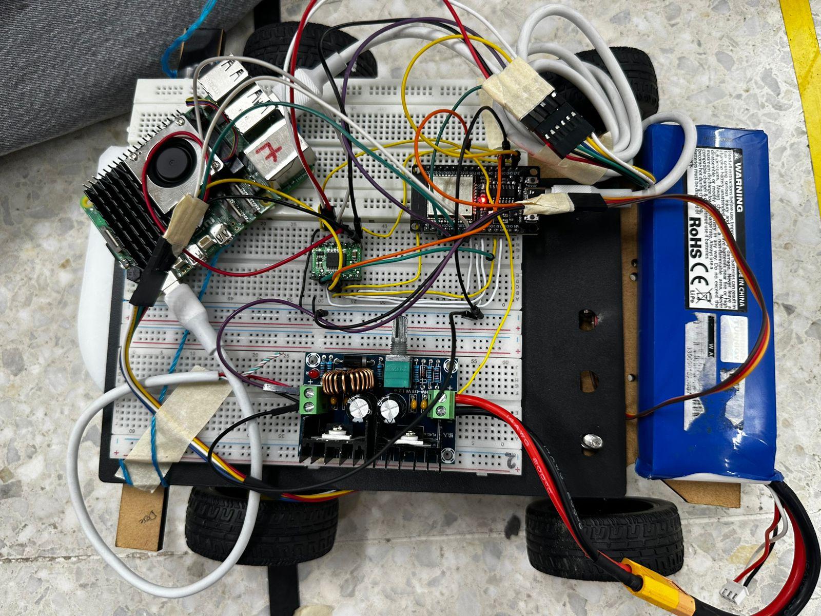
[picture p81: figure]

→

### →https://drive.google.com/file/d/1IukeA77VsIOf_r7bcGVIeBXOnHwp14YX/view?usp=sharing

### →https://drive.google.com/file/d/1d4cdvxYtnOICpQwrOCKsQMWLrq0Vj-ZI/view?usp=sharing

### https://github.com/Espitiass/G7ACKER

MATERIALES | CANT. | UNIDAD DE MEDID A | COSTO UNITARIO SIN IVA | IVA | COSTO TOTAL | JUSTIFICACIÓN
Conector TX60 MAC | 1 | | 4860 | 1140 | 6000 | Permite una conexión segura de alta corriente entre la batería y el sistema, evitando pérdidas de energía y sobrecalentamientos.
Regulador de Voltaje (XL4016 de 8A) | 1 | | 19440 | 4560 | 24000 | Regulación de voltaje de entrada (7–12V) a 5V estable para alimentación segura de la Raspberry Pi
Cable USB a TIPO c | 2 | | 8100 | 3800 | 20000 | Facilita la alimentación y comunicación estable de la Raspberry Pi 5.
SEMESTRE INTEGRADOR | CÓDIGO | FI-F-001
BITÁCORA | VERSIÓN | 2

LM2596 | 1 | 6480 | 1520 | 8000 | Proporciona un voltaje estable de 3.3V para sensores y módulos electrónicos.
ESP 32 | 1 | 27540 | 6460 | 34000 | Gestiona la comunicación y control de periféricos, apoyando el procesamiento del sistema.
COMPROMISOS | RESPONSABLE | FECHA DE INICIO | FECHA FIN | APRENDIZAJES CLAVE
Mejorar la planificación y elaboración de la bitácora para las semanas 8 y 9, asegurando que los procesos y actividades definidos puedan ejecutarse de manera completa y organizada dentro del tiempo establecido. | Julian | 19/03/2026 | 20/03/2026 | Fortalecimiento en la planificación y estructuración de la bitácora, garantizando mayor claridad, organización y cumplimiento de las actividades propuestas en futuras semanas.

### OBSERVACIONES DOCENTES

OBSERVACIÓN | FECHA | DOCENTE
SEMESTRE INTEGRADOR | CÓDIGO | FI-F-001
BITÁCORA | VERSIÓN | 2

### CONTROL DE CAMBIOS ESPACIO SOLO PARA CAMBIOS DEL FORMATO

RESPONSABLE DEL CAMBIO | JUSTIFICACIÓN DEL CAMBIO | DESCRIPCIÓN DEL CAMBIO | FECHA DE CAMBIO | NÚMERO DEL CAMBIO
Angie Tatiana Rengifo Oviedo | Se encontró que el formato anterior le faltaba información y era confuso para el proceso de ABP | Modificación de parámetros en la documentación de la ejecución. | 30/01/2026 | Versión 2
SEMESTRE INTEGRADOR | CÓDIGO | FI-F-001
BITÁCORA | VERSIÓN | 2

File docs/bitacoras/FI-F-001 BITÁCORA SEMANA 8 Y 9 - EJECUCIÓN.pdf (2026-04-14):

## INGENIERÍA MECATRÓNICA

SEMESTRE INTEGRADOR | CÓDIGO | FI-F-001
BITÁCORA | VERSIÓN | 2

### IDENTIFICACIÓN DEL PROYECTO

### NOMBRE DEL PROYECTO: ATLAS

### INTEGRANTES DEL EQUIPO

NOMBRE | APELLIDOS | CÓDIGO | ROL EN EL PROYECTO
VANESA | GALEANO FRANCO | 1109292401 | MECÁNICA
NOMBRE | APELLIDOS | CÓDIGO | ROL EN EL PROYECTO
SOFIA SALOMÉ | ESPITIA JIMENEZ | 1080046389 | DISEÑADORA
NOMBRE | APELLIDOS | CÓDIGO | ROL EN EL PROYECTO
JULIÁN ANDRÉS | GARCIA | 1088004478 | ELECTRÓNICO
NOMBRE | APELLIDOS | CÓDIGO | ROL EN EL PROYECTO
JOSE LISANDER | HURTADO | 1088028747 | PROGRAMADOR

### FECHA DE ENTREGA (DD/MM/AA): 20/03/2026

### SEMANA NO: 8 Y 9 RESPONSABLE DEL REGISTRO: Julián Andrés García Correa

ETAPA/FASE DEL PROYECTO: Diseño de PCB e integración de sensores.

### PLANEACIÓN

### OBJETIVOS (Definidos en la reunión de planeación): 1. Modificación del sistema ackerman

2. Compra de sensores.
3. Integración de sensores y verificación por medio de protoboard.
4. Diseño de PCB y verificación de todas las conexiones, actividad no realizada en las semanas 6 y 7.
5. Envío a fabricación de PCB en China.

### 6. Programar el sistema de visión artificial utilizando la cámara IMX219 conectada a una Raspberry Pi, que permita detectar y reconocer líneas 7. Organizar y actualizar la documentación técnica (bitácora)

ACTIVIDAD | FECHA DE INICIO | FECHA FINAL | MATERIALES | PRESUPUE STO | RIESGOS POTENCIALES | ALTERNATIVAS | ENTREGABLE | RESPONSABLE
Compra de sensores | 24-03-2026 | 25-3-2026 | Sensor infrarrojo TCR5000, | $ 30.000 | Dificultad para conseguir | Comprar en línea. | Materiales comprados | Julián

SEMESTRE INTEGRADOR | CÓDIGO | FI-F-001
BITÁCORA | VERSIÓN | 2
ACTIVIDAD | FECHA DE INICIO | FECHA FINAL | MATERIALES | PRESUPUE STO | RIESGOS POTENCIALES | ALTERNATIVAS | ENTREGABLE | RESPONSABLE
| | | Final de carrera, Endstop, sensor ultrasónico. | | el sensor infrarrojo TCR
Modificación del sistema ackerman | 23-3-2 026 | 24-3-20 26 | Impresora 3D, computador, software fusion | $439.344 | Funcionami ento irregular del ackerman | Cambio del diseño en fusion | Ackerman funcionando correctamen te | Julián.
Conexión de sensores a la protoboard | 24-03-2026 | 25-3-2026 | Sensores | $ 439.344 | Malas conexiones de sensores y funcionami ento irregular de los mismos. | Probar con otra referencia de sensores en caso de que los seleccionados no funciones correctamente | Sensores funcionando con protoboard. | Julián.
Integración de sensores al chasis. | 25-3-2026 | 26-03-2 026 | Sensores | $ 439.344 | Dificultad para integrar los sensores al chasis | Hacer un ensamblaje en fusión | Sensores integrados al chasis del robot | Julián.
Diseño de PCB en Fusion | 24-3-2 026 | 25-03-2 026 | Software de diseño (Fusion), computador. | $ 439.344 | Dificultad para encontrar los component es en el software con las mismas medidas de piezas físicas. | Consultar a compañeros y profesores de clase. | PCB diseñada en Fusion. | Sofía.
Verificación de PCB | 25-3-2 026 | 26-3-20 26 | Software de diseño (Fusion), computador. | $ 439.344 | No incluir la totalidad de component es, falta de conexiones | Solicitar a los profesores encargados una revisión de la pcb en fusion. | PCB verificada por integrante del grupo. | Vanesa.

SEMESTRE INTEGRADOR | CÓDIGO | FI-F-001
BITÁCORA | VERSIÓN | 2
ACTIVIDAD | FECHA DE INICIO | FECHA FINAL | MATERIALES | PRESUPUE STO | RIESGOS POTENCIALES | ALTERNATIVAS | ENTREGABLE | RESPONSABLE
Envío a fabricación de PCB | 27-3-2 026 | 27-03-2 026 | Página de fabricante de PCB en China. | $60.000 | Solicitud de fabricación rechazada por archivos no compatible s. | Seguimiento a la solicitud, verificación de correo de confirmación | No de solicitud de fabricación. | Sofia.
Configuración de cámara IMX219 para reconocimiento de líneas. | 25-03-2026 | 27-03-2 026 | Robot prototipo, camara IMX219, Raspberry PI5 | $ 439.344 | Posicionam iento incorrecto de la cámara la cual no detecta líneas. | Mejorar diseño 3D para el posicionamien to de la cámara | Cámara IMX219, reconociend o líneas. | Jose.
Programación de sensores con Raspberry pi 5. | 30-3-2 026 | 31-3-20 26 | Computador, robot prototipo, Raspberry pi 5 | $ 439.344 | Indicacione s incorrectas de los sensores | Cambio en la programación inicial. | Sensores funcionando correctamen te en Robot | José.
Pruebas en pista para la verificación de los sensores. | 31-03-2026 | 01-04-2 026 | Computador, robot prototipo, Raspberry pi 5 | $ 219.672 | Los sensores no reconocen las señales de la pista. | Calibración de sensores, cambio en la programación. | Robot prototipo con integración correcta de sensores | José.
Ubicación definitiva de componentes eléctricos y electrónicos en robot | 31-03-2026 | 01-04-2 026 | Sensores, reguladores de voltaje, esp32, raspberry pi 5, driver | $ 219.672 | Distribució n irregular que genere recalentam iento en component es | Solicitar recomendacio nes de distribución a los profesores guías. | Archivo esquemático con componente s definitivos. | Julián
Bitácora 4 Programación semana 10 y 11 | 02-04-2026 | 03-04-2 026 | Computador, Google Docs | $ 219.672 | Inconsisten cias en informació n | Validación con el equipo | Bitácora de la semana 10 y 11 | José

SEMESTRE INTEGRADOR | CÓDIGO | FI-F-001
BITÁCORA | VERSIÓN | 2

### EJECUCIÓN

ACTIVIDAD | FECHA INICIO | FECHA FIN | OPORTUNIDADES DE MEJORA O DESAFÍOS ENCONTRADOS | ACCIONES CORRECTIVAS O DE MEJORA | ESTADO DE ENTREGABLE | RESPONSABLE
Compra de sensores | 24/3/2026 | 25/3/2026 | N/A | N/A | Completado | Julián
Modificación del sistema ackerman | 23/3/2026 | 24/3/2026 | El diseño anterior del sistema ackerman no permitía un buen posicionamiento de las ruedas delanteras. | Cambio del diseño anterior. | Completado | Julián
Conexión de sensores a la protoboard | 24-03-2026 | 25-3- 2026 | No se realizó la actividad | | Incompleto | Julián
Integración de sensores al chasis. | 25-3- 2026 | 26-03-2026 | No se realizó la actividad | | Incompleto | Julián
Diseño de PCB en Fusion | 24-3-2026 | 25-03-2026 | Durante la revisión del diseño esquemático en fusion se adicionaron borneras las cuales facilitan la conexión de los reguladores de voltaje | La recomendación de los profesores relacionada con la revisión del diseño PCB es muy util ya que se puede identificar errores y mejoras al diseño. | Completado | Sofia.
Verificación de PCB | 25-3-2026 | 26-3-2026 | Adición de componentes que facilitan las conexiones | Cambios en el diseño PCB | Completado | Todos
Envío a fabricación de PCB | 27-3-2026 | 27-03-2026 | N/A | N/A | Incompleto, ya que se aumentó el plazo para enviar a fabricar la PCB. | Sofia.
Configuración de cámara IMX219 para reconocimient o de líneas. | 25-03-2026 | 27-03-2026 | Dificultad para la programación de la cámara | Búsqueda de librerías compatibles con la cámara IMX219 | Completado | José
Programación de sensores con Raspberry pi 5. | 30-3-2026 | 31-3-2026 | N/A | N/A | Incompleto | José

SEMESTRE INTEGRADOR | CÓDIGO | FI-F-001
BITÁCORA | VERSIÓN | 2
Pruebas en pista para la verificación de los sensores. | 31-03-2026 | 01-04-2026 | N/A | N/A | Incompleto | José
Ubicación definitiva de componentes eléctricos y electrónicos en robot | 31-03--2026 | 01-04-2026 | Desafío para ubicar todos los componentes de manera estratégica. | Hacer el montaje de todos los componentes en fusión para revisar el tema de espacios. | Parcial | Vanesa-Sofia
Bitácora 4 Programación semana 10 y 11 | 02-04-2026 | 03-04-2026 | N/A | N/A | Completado | Julián

### ANÁLISIS DE CAUSA RAÍZ DESAFÍOS ENCONTRADOS:

Durante el desarrollo del robot autónomo en las semanas 8 y 9, bajo la metodología ABP, surgieron varios desafíos importantes. Uno de los principales estuvo relacionado con el cambio en el diseño del sistema Ackermann, ya que las llantas no presentaban un adecuado asentamiento con respecto al piso, lo que ocasionaba un funcionamiento irregular del sistema. Esta situación implicó trabajo adicional en el rediseño, la impresión de nuevos componentes y su posterior integración al robot.

Otro desafío significativo fue la programación de la cámara, debido a que fue necesario realizar múltiples pruebas con diferentes librerías para cumplir con el objetivo de detección de líneas. Actualmente, el sistema ya permite la detección de líneas de color amarillo y negro, y además es capaz de identificar el sentido del carril.

### EVIDENCIA (FOTOGRAFÍA Y ENLACE A REPOSITORIO):

### Link repositorio. https://github.com/Espitiass/G7ACKER

Compra de sensores.

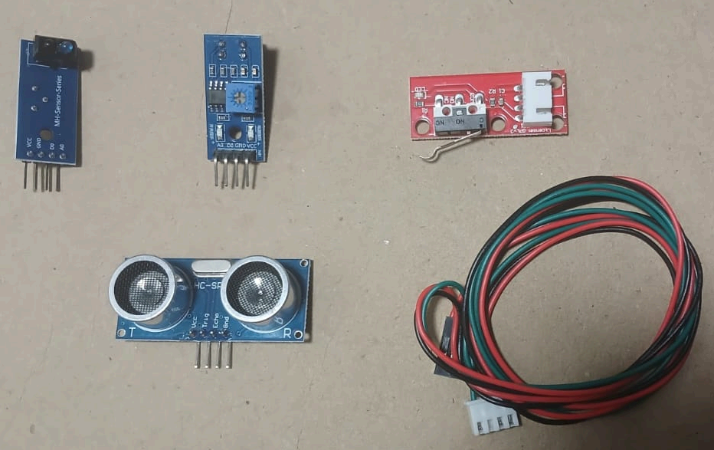
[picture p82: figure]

SEMESTRE INTEGRADOR | CÓDIGO | FI-F-001
BITÁCORA | VERSIÓN | 2

### Diseño CAD Ackerman Anterior/Actual

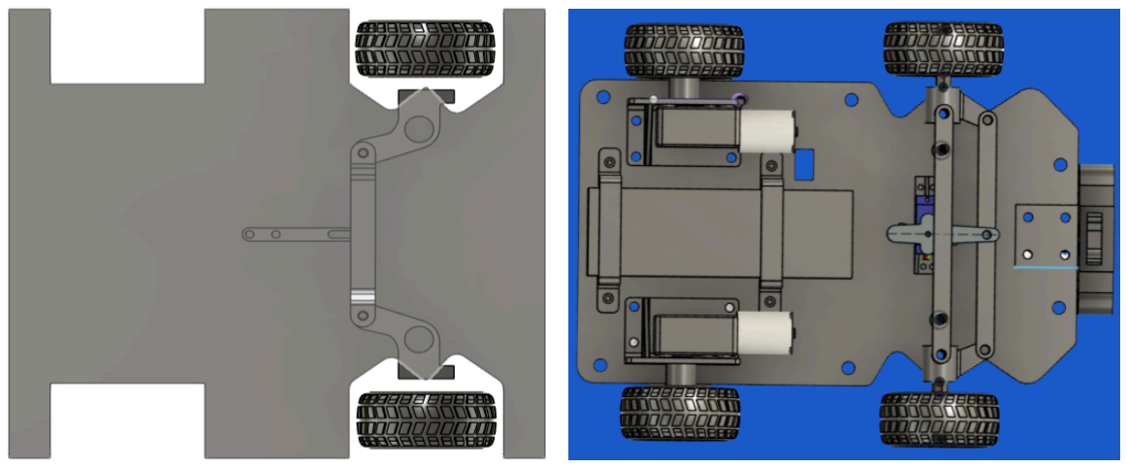
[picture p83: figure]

### Sistema ackerman Anterior/Actual

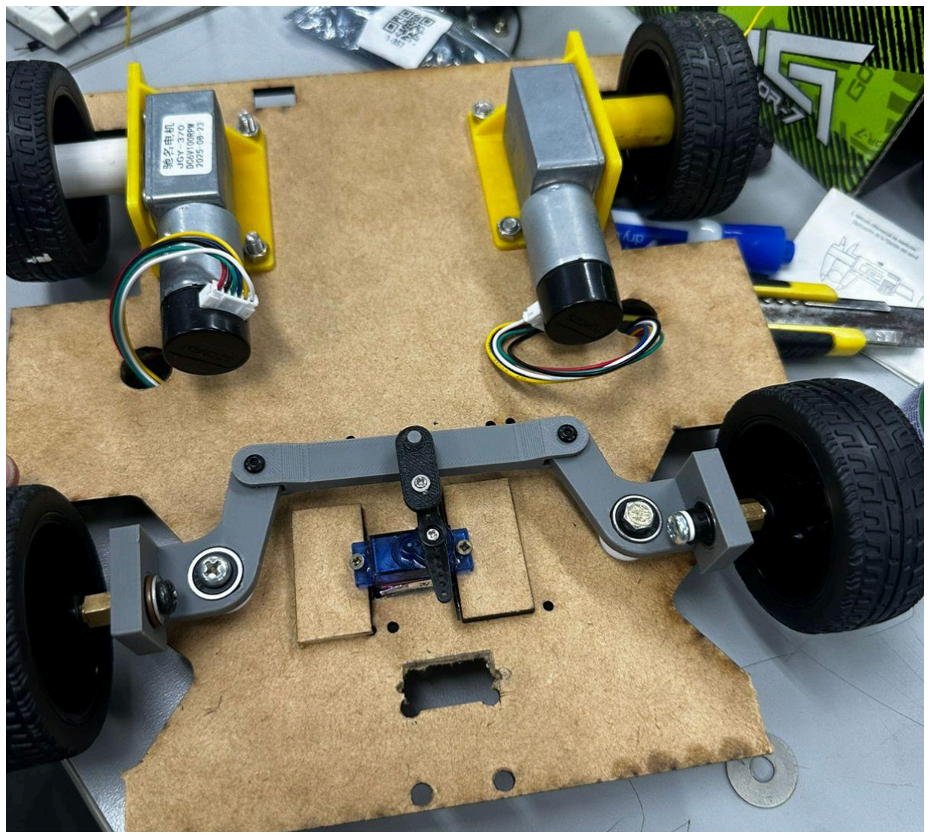
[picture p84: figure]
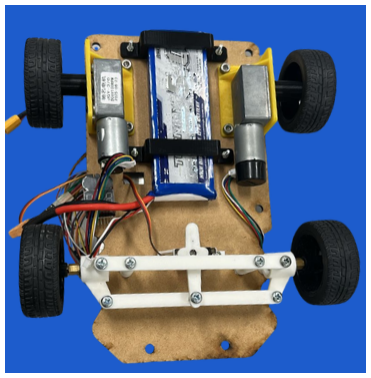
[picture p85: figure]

SEMESTRE INTEGRADOR | CÓDIGO | FI-F-001
BITÁCORA | VERSIÓN | 2

### Evidencia PCB

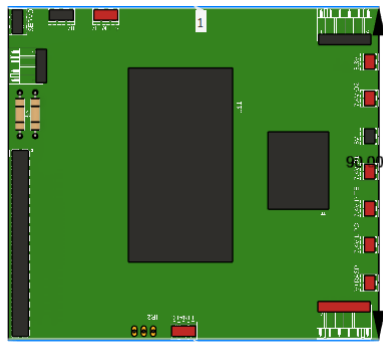
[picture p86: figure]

Evidencia programación cámara.

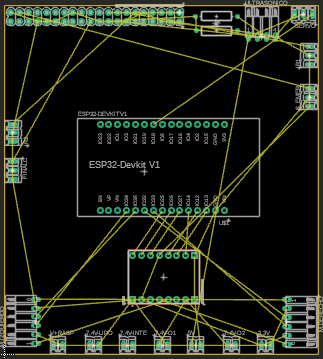
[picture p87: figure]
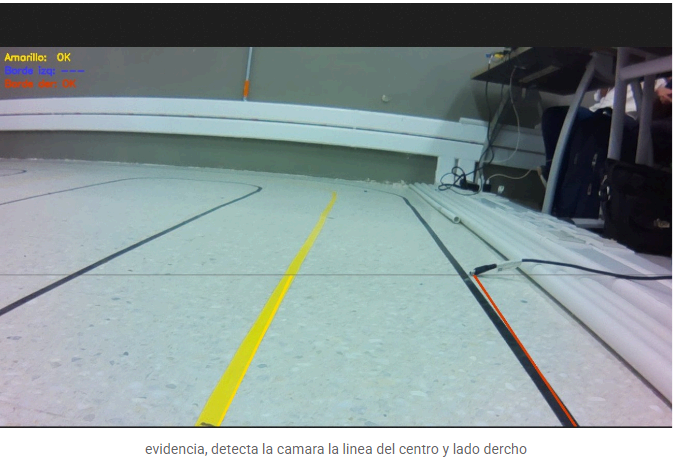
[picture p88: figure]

SEMESTRE INTEGRADOR | CÓDIGO | FI-F-001
BITÁCORA | VERSIÓN | 2

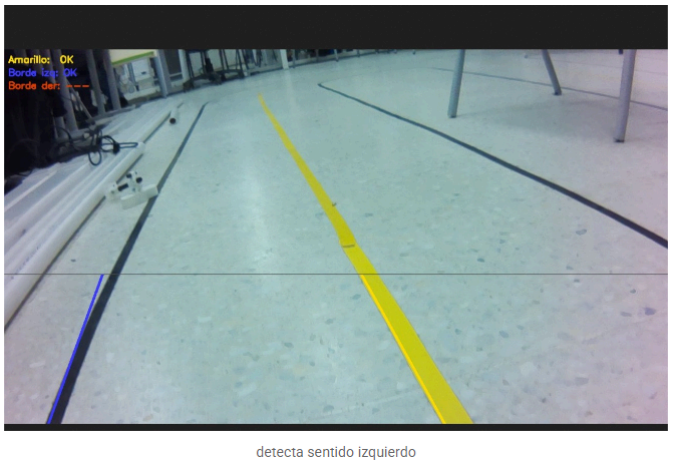
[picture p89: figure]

Evidencia ubicación de componentes electrónicos.

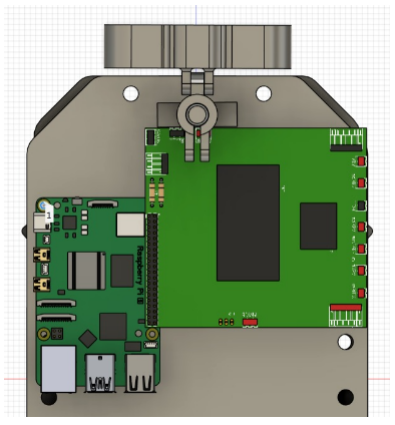
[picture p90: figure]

→

SEMESTRE INTEGRADOR | CÓDIGO | FI-F-001
BITÁCORA | VERSIÓN | 2

→

→

MATERIALES | CANT. | UNIDAD DE MEDIDA | COSTO UNITARIO SIN IVA | IVA | COSTO TOTAL | JUSTIFICACIÓN
Sensor Ultrasonido | 1 | Unidad | 6480 | 1520 | 8000
Modulo Seguidor de línea TCRT5000 | 2 | Unidad | 9720 | 2280 | 12000
Final de carrera | 1 | Unidad | 4860 | 1140 | 6000
COMPROMISOS | RESPONSABLE

### FECHA DE INICIO

### FECHA FIN

### APRENDIZAJES CLAVE

### OBSERVACIONES DOCENTES

OBSERVACIÓN | FECHA | DOCENTE

SEMESTRE INTEGRADOR | CÓDIGO | FI-F-001
BITÁCORA | VERSIÓN | 2

### CONTROL DE CAMBIOS ESPACIO SOLO PARA CAMBIOS DEL FORMATO

RESPONSABLE DEL CAMBIO | JUSTIFICACIÓN DEL CAMBIO | DESCRIPCIÓN DEL CAMBIO | FECHA DE CAMBIO | NÚMERO DEL CAMBIO
Angie Tatiana Rengifo Oviedo | Se encontró que el formato anterior le faltaba información y era confuso para el proceso de ABP | Modificación de parámetros en la documentación de la ejecución. | 30/01/2026 | Versión 2

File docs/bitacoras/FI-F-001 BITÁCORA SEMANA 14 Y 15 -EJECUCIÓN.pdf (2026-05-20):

### IDENTIFICACIÓN DEL PROYECTO

### NOMBRE DEL PROYECTO: ATLAS

### INTEGRANTES DEL EQUIPO

NOMBRE | APELLIDOS | CÓDIGO | ROL EN EL PROYECTO
VANESA | GALEANO FRANCO | 1109292401 | MECÁNICA
NOMBRE | APELLIDOS | CÓDIGO | ROL EN EL PROYECTO
SOFIA SALOMÉ | ESPITIA JIMENEZ | 1080046389 | DISEÑADORA
NOMBRE | APELLIDOS | CÓDIGO | ROL EN EL PROYECTO
JULIÁN ANDRÉS | GARCIA | 1088004478 | ELECTRÓNICO
NOMBRE | APELLIDOS | CÓDIGO | ROL EN EL PROYECTO
JOSE LISANDER | HURTADO | 1088028747 | PROGRAMADOR

### FECHA DE ENTREGA (DD/MM/AA): 01/05/2026 SEMANA NO: 14 Y 15 RESPONSABLE DEL REGISTRO: Vanesa Galeano

ETAPA/FASE DEL PROYECTO: Lectura de QRs e Integración de sistemas completos.

### PLANEACIÓN

### OBJETIVOS (Definidos en la reunión de planeación):

1. Construcción e integración mecánica del robot: Ensamblar la base de carga, paredes y estructura completa del robot asegurando precisión en cortes y piezas.
2. Desarrollo y validación de la programación: Implementar funciones clave como la evasión de obstáculos y la dirección Ackerman, integrando los scripts en los microprocesadores.
3. Documentación técnica y de usuario: Elaborar manuales, bitácoras y repositorios organizados que respalden el uso, mantenimiento y replicación del robot.
4. Comunicación y difusión de resultados: Preparar presentaciones, informes finales y artículos publicables que reflejen el proceso, hallazgos y aportes del proyecto.
5. Pruebas y demostración del funcionamiento: Afinar el código, grabar videos del desempeño del robot y validar su operación en escenarios reales para mostrar resultados tangibles.
ACTIVIDAD | FECHA DE INICIO | FECHA FINAL | MATERIALES | PRESUPU EST O | RIESGOS POTENCIALE S | ALTERNATIVAS | ENTREGABL E | RESPONSABL E
Integración total Mecánica – Base de carga y paredes | 4-5-20 26 | 6-5-2 026 | Bases del robot, Cubierta, tornillería, herramientas | $ 439.344 | Problemas al momento de corte de las bases y el ensamble general | Verificar bien las piezas antes de mandar cortar y/o repetir la pieza | Estructura del robot completa m ente armada | Julián

Manual de usuario | 6-5-20 26 | 8-5-2 026 | Computador, Google Docs, GitHub | $ 219.672 | Retrasos en la programación y funcionamient o real y del robot para validar el manual | Validación con el equipo | Manual de usuario en word | Julián
Evasión de obstáculos | 4-5-20 26 | 8-5-2 026 | Computado r, robot prototipo, Raspberry pi 5, Visual Studio Code | $ 878.688 | Errores en el funcionamient o de la dirección ackerman y velocidad de motores. | Verificar rango de movilidad y señal de envío. | Script de ovación de obstáculo completo | Vanesa
Integración total Programación y ajustes finales | 4-5-20 26 | 8-5-2 026 | Computado r, robot prototipo, Raspberry pi 5, Visual Studio Code | $ 439.344 | Bugs del código y de comunicaci ón al momento de unificar | Unificación secuencial, documentad a y experimenta | Scripts en repositori o y cargados en los microproc e sadores. | Vanesa
Videos funcionamiento del robot | 13-5-20 26 | 13-5-2 026 | Celular móvil | $ 50.000 | Error del robot en el circuito | Afinación de codigo | Videos del funciona miento | Vanesa
Presentación final | 4-5-20 26 | 6-5-2 026 | Computador, Google Docs | $ 219.672 | Inconsisten cia en la información , errores en la presentació n | Validación con el equipo y con la profesora Tatiana | Presentaci ón final | José
Informe final | 4-5-20 26 | 15-5-2 026 | Computador, Google Docs, github, información del equipo | $ 219.672 | Inconsisten cia s en información , información incompleta en el repositorio | Validación con el equipo y con la profesora Tatiana | Informe final | Sofia
Articulo publicable | 4-5-20 26 | 15-5-2 026 | Computador, Google Docs, github, información del equipo | $ 219.672 | Inconsisten cia s en información , información incompleta en el repositorio | Validación con el equipo y con la profesora Tatiana | Articulo publicable | Sofia

Integración total Documentación | 13-5-2 026 | 15-5-2 026 | Computado r, Google Docs, GitHub | $ 219.672 | Inconsisten cia s en información , información incompleta en el repositorio | Validación con el equipo, actualización n constante del repositorio | Repositori o completo y organizad o | Vanesa
Bitácora 7 -Planeación semana 16 y 17 | 15-05-2 026 | 15-05-2026 | Computado r, Google Docs | $ 219.672 | Inconsisten cia en la información | Validación con el equipo | Bitácora 6 -Planeació n semana 16 y 17 | Julian

### EJECUCIÓN

ACTIVIDAD | FECHA INICIO | FECHA FIN | OPORTUNIDAD ES DE MEJORA O DESAFÍOS ENCONTRADOS | ACCIONES CORRECTIVAS O DE MEJORA | ESTADO DE ENTREGABLE | RESPONSABLE
Integració n total Mecánica – Base de carga y paredes | 4-5-2026 | 6-5-2026 | se encontraron inconvenientes en algunas piezas debido algunas diferencias en los cortes | Se realizó verificación de dimensiones manuales, se hicieron los correspondientes ajustes | Completado | Julian
Manual de usuario | 6-5-2026 | 8-5-2026 | Dificultad para documentar algunas funciones debido a los cambios constantes en la programación | Se realizaron validación continua con el equipo permanentemente del manual conforme avanza el desarrollo del robot | En proceso | Vanesa
Evasión de obstáculo s | 4-5-2026 | 8-5-2026 | N/A | N/A | Incompleto | Vanesa
Integración total Programaci ón y ajustes finales | 4-5-2026 | 8-5-2026 | se presentaron errores de comunicación de microcontroladores | Se reorganizó la estructura del código, realizando pruebas individuales antes de integrar todo | En proceso | Vanesa
Videos funcionamient o del robot | 13-5-2026 | 13-5-2026 | Durante las pruebas el robot presento fallos de seguimiento | se realizaron ajustes a la programación para que este corrigiera | En proceso | Vanesa
Presentación final | 4-5-2026 | 6-5-2026 | Existía inconsistencias visuales en algunas diapositivas | se reorganizó la información, se mejoró el diseño visual y se validó el | Completado | Jose

| | | | contenido
Informe final | 4-5-2026 | 15-5-2026 | se identificaron informaciones incompletas por parte de la docente en algunos apartados técnicos | se consolidó toda la información para realizar los respectivos cambios | En proceso | Sofia
Artículo publicable | 4-5-2026 | 15-5-2026 | Dificultad para sintetizar toda la información técnica | se estructuró el artículo de forma que toda la información técnica quedara acorde | Completado | Sofia
Integración total Documentació n | 13-5-2026 | 15-5-2026 | Falta de organizar el repositorio y versiones desactualizadas | Se reorganizó el GitHub, en la actualización. | Completado | Vanesa
Bitácora 7 -Planeación semana 16 y 17 | 15-05-2026 | 15-05-2026 | Dificultad para consolidar toda la información los tiempos | se realizaron reunión grupal para darle seguimiento y validación | Completado | Julian

### ANÁLISIS DE CAUSA RAÍZ DESAFÍOS

### ENCONTRADOS: EVIDENCIA (FOTOGRAFÍA Y ENLACE A

### REPOSITORIO):

### →Repositorio (https://github.com/Espitiass/G7ACKER)

→

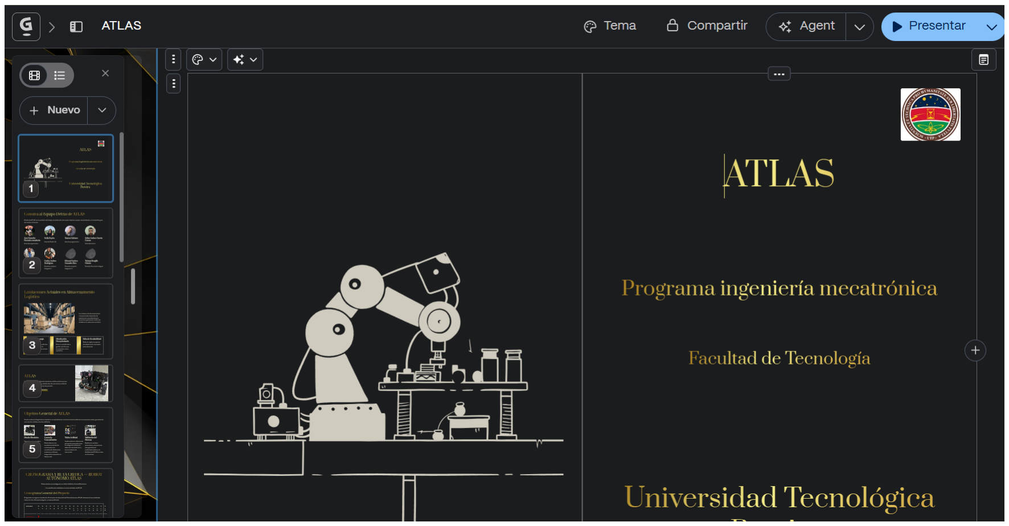
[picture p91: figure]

→

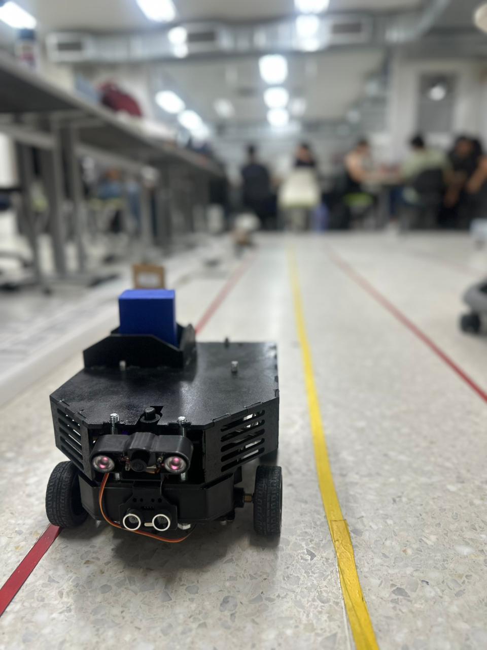
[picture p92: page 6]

→

MATERIALES; CANT.; UNIDA D DE MEDID A; COSTO UNITARIO SIN IVA; IVA; COST; O TOTAL; JUSTIFICACIÓN

COMPROMISOS | RESPONSABLE | FECHA DE INICIO | FECHA FIN | APRENDIZAJES CLAVE
Hacer una re organización para que poder llevar a cabo, todas las actividades propuestas en las semanas siguientes | Vanesa | 14/05/2026 | 15/05/2026 | Se comprendió la importancia de una adecuada reorganización y planificación del tiempo para optimizar el desarrollo de las actividades del proyecto, permitiendo mejorar la distribución de tareas

### OBSERVACIONES DOCENTES

### CONTROL DE CAMBIOS ESPACIO SOLO PARA CAMBIOS DEL FORMATO

RESPONSABLE DEL CAMBIO | JUSTIFICACIÓN DEL CAMBIO | DESCRIPCIÓN DEL CAMBIO | FECHA DE CAMBIO | NÚMERO DEL CAMBIO
Angie Tatiana Rengifo Oviedo | Se encontró que el formato anterior le faltaba información y era confuso para el proceso de ABP | Modificación de parámetros en la documentación de la ejecución | 30/01/2026 | Versión 2
OBSERVACIÓN | FECHA | DOCENTE

INGENIERÍA MECATRÓNICA
SEMESTRE INTEGRADOR | CÓDIGO | FI-F-001
BITÁCORA | VERSIÓN | 2

INGENIERÍA MECATRÓNICA
SEMESTRE INTEGRADOR | CÓDIGO | FI-F-001
BITÁCORA | VERSIÓN | 2

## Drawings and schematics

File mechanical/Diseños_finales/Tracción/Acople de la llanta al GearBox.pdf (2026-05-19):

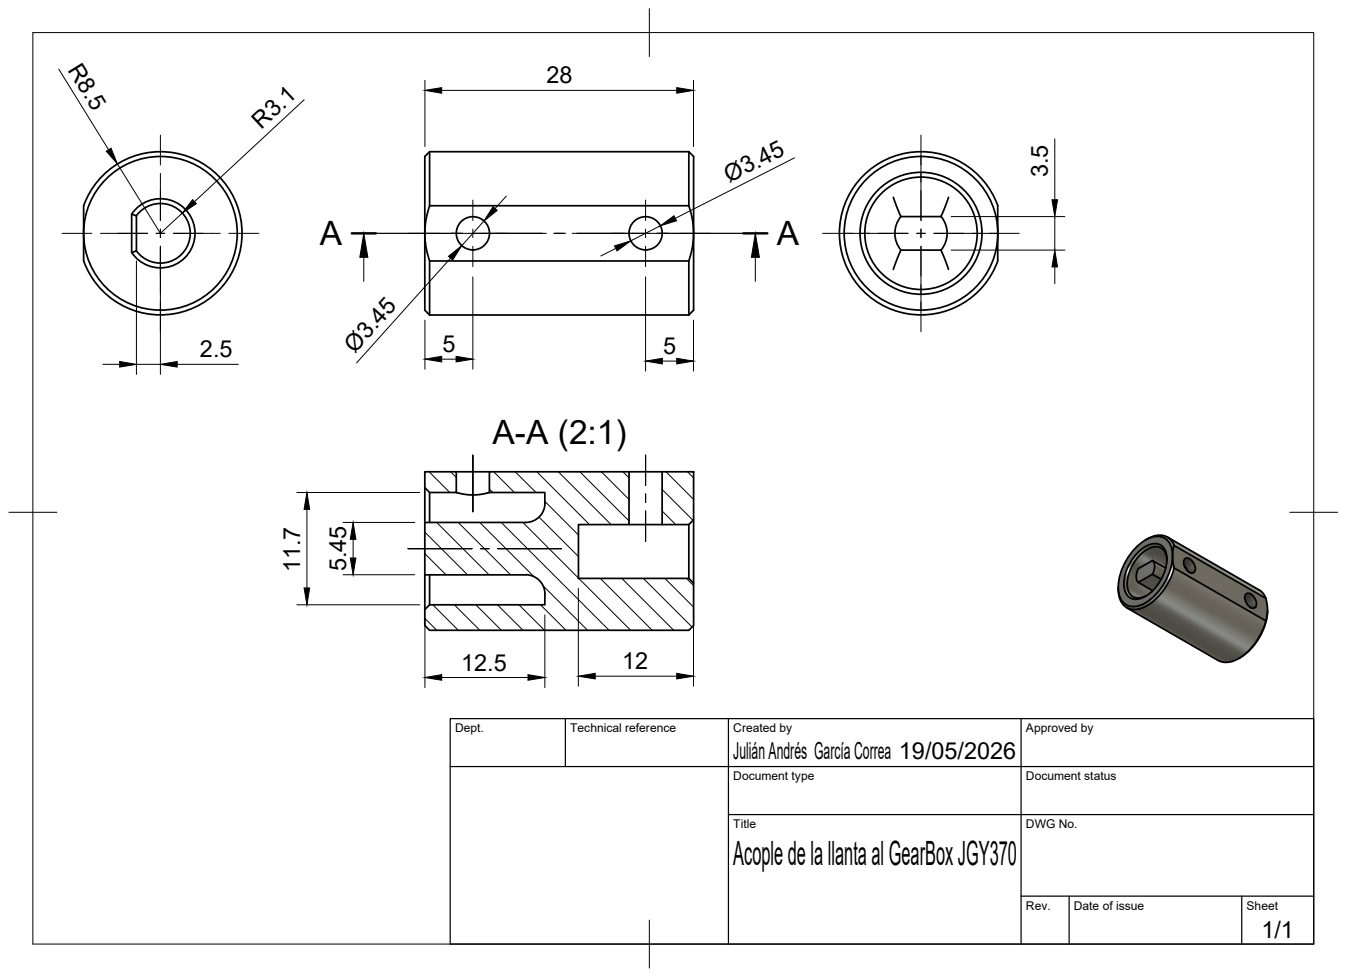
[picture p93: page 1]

Dept. | Technical reference | Created by Julián Andrés García Correa 19/05/2026 | Approved by

Document type | Document status

Title Acople de la llanta al GearBox JGY370 | DWG No.

Rev. | Date of issue | Sheet 1/1

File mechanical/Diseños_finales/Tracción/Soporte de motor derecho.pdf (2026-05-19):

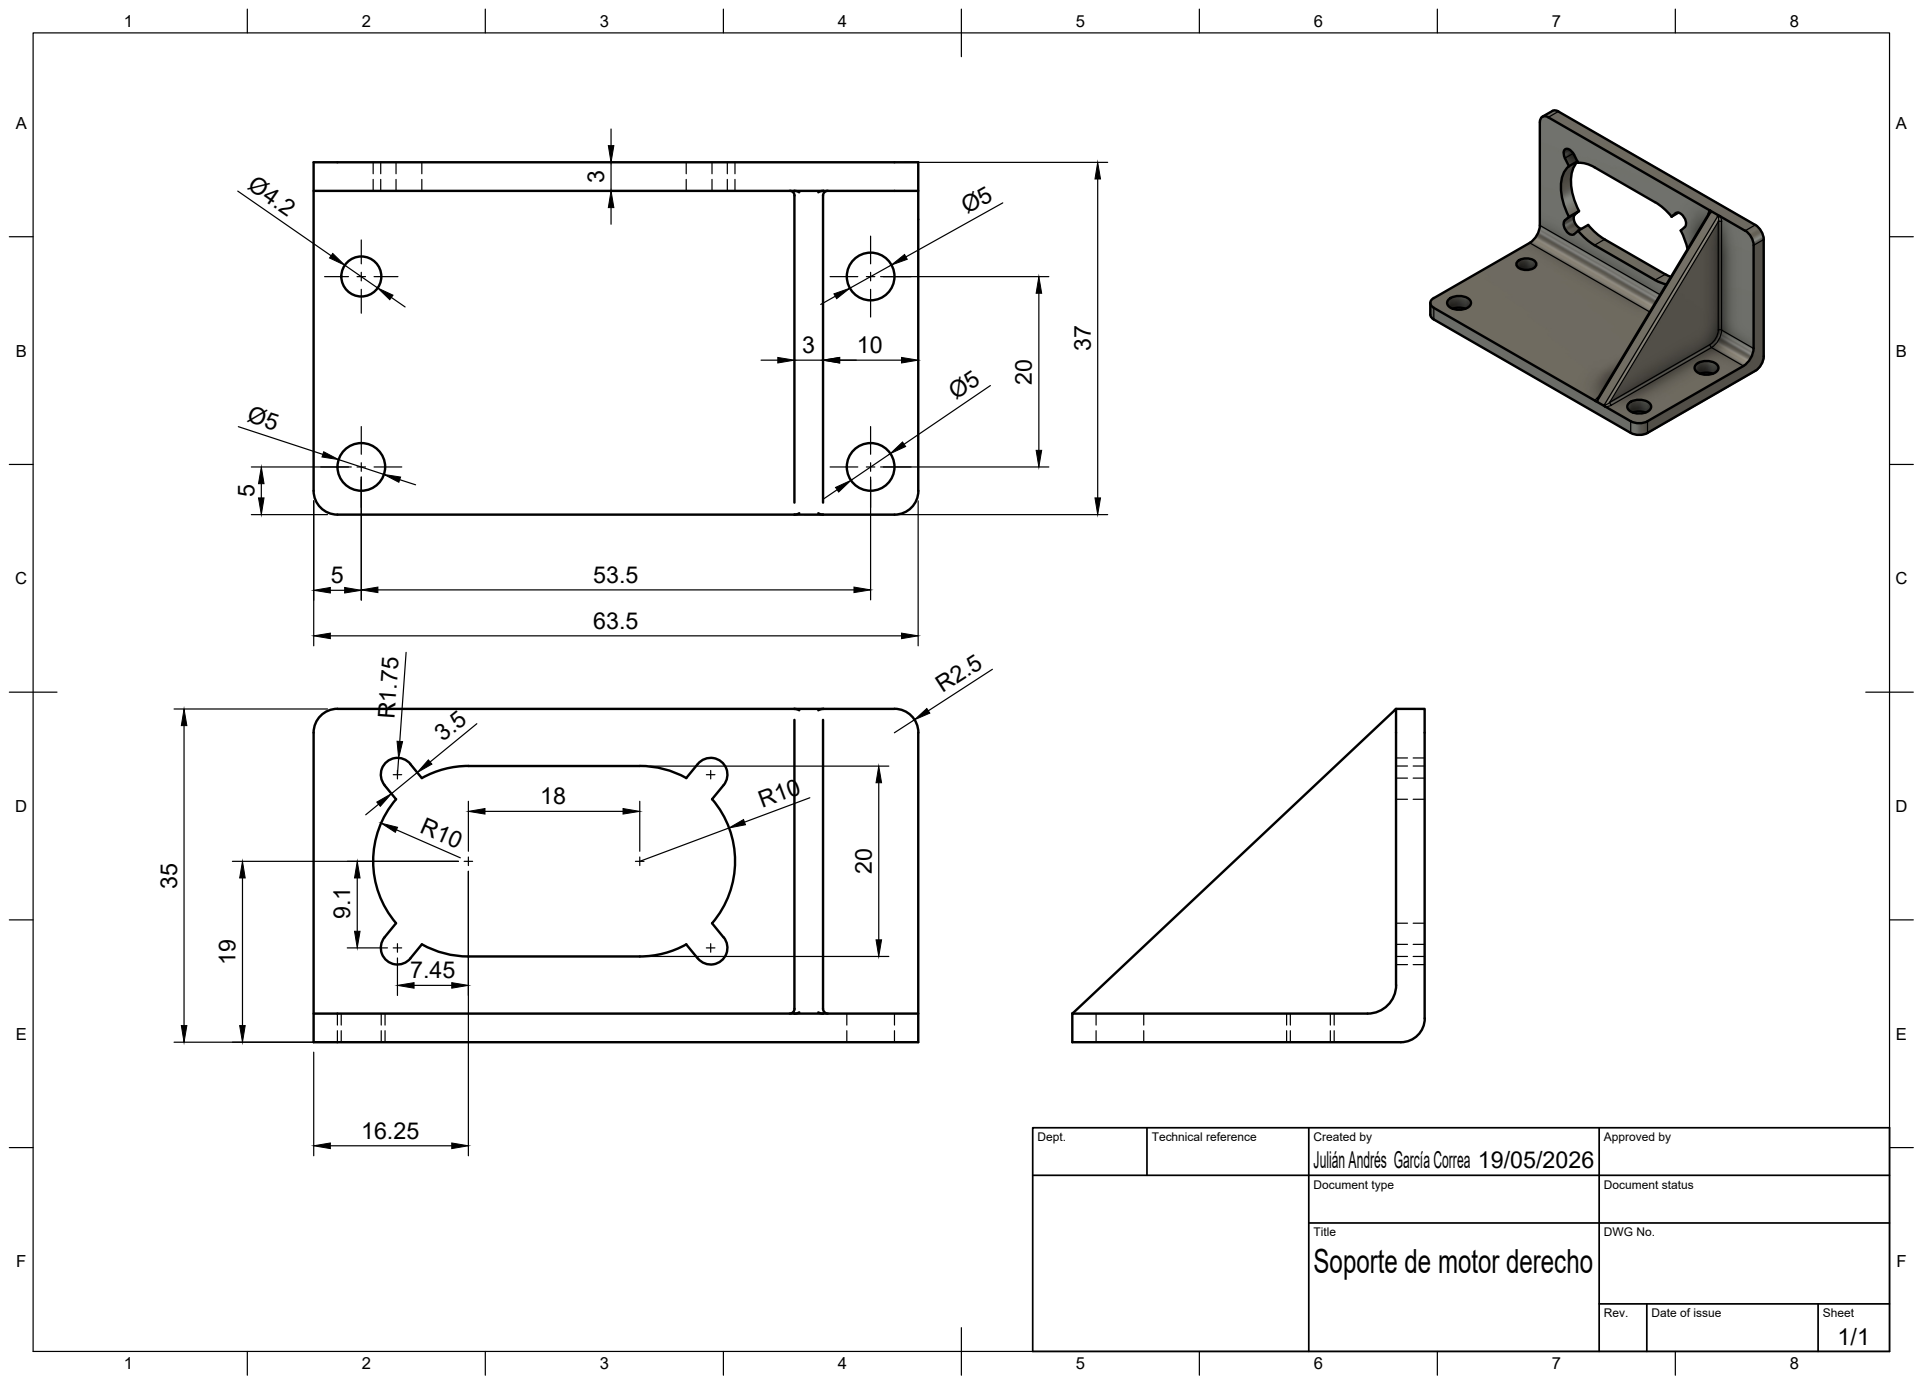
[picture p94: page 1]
Title; DWG No.; Rev.; Date of issue; Sheet

Dept. | Technical reference | Created by Julián Andrés García Correa 19/05/2026 | Approved by

Document type | Document status

Soporte de motor derecho

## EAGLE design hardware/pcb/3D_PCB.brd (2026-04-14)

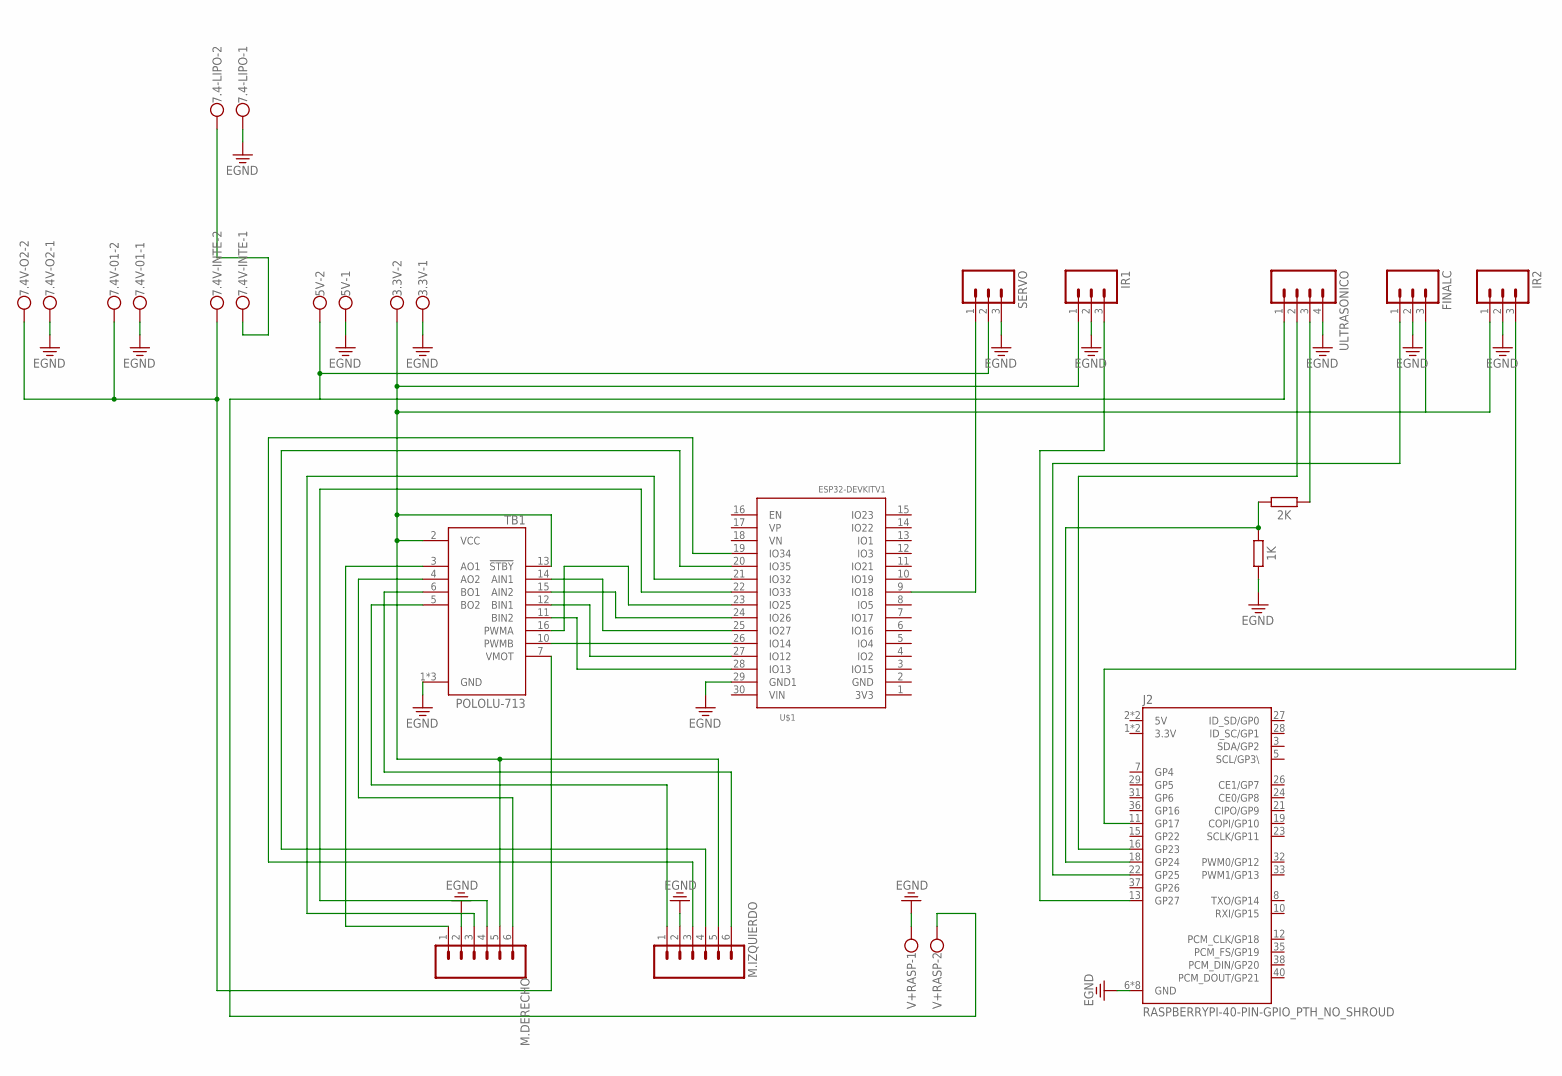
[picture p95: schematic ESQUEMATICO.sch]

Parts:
1K, 2K: R_AXIAL-11.7MM-PITCH; RESAD1176W63L850D250B
3.3V, 5V, 7.4-LIPO, 7.4V-01, 7.4V-INTE, 7.4V-O2: W237-102
FINALC: MA03; 03P
IR1, IR2: MA03; 03P
J2: RASPBERRYPI-40-PIN-GPIO_PTH_NO_SHROUD; 2X20
M.DERECHO, M.IZQUIERDO: MA06; 06PA
SERVO: MA03; 03P
TB1: POLOLU-713; SHIELD_POLOLU-713
U$1: ESP32DEVKITV1; ESP32-DEVKITV1
ULTRASONICO: MA04; 04PA
V+RASP: W237-102

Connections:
3.3V: 3.3V.2, FINALC.3, IR1.1, IR2.1, J2.1 (3.3V), J2.17 (3.3V), M.DERECHO.5, M.IZQUIERDO.5, TB1.2 (VCC), TB1.13 (!STBY)
5V: 5V.2, J2.2 (5V), J2.4 (5V), SERVO.2, ULTRASONICO.1, V+RASP.2
7.4V: 7.4-LIPO.2, 7.4V-INTE.1
EGND: 1K.2, 3.3V.1, 5V.1, 7.4-LIPO.1, 7.4V-01.1, 7.4V-O2.1, FINALC.2, IR1.2, IR2.2, J2.6 (GND), J2.9 (GND), J2.14 (GND), J2.20 (GND), J2.25 (GND), J2.30 (GND), J2.34 (GND), J2.39 (GND), M.DERECHO.2, M.IZQUIERDO.2, SERVO.3, TB1.1 (GND), TB1.8 (GND), TB1.9 (GND), U$1.29 (GND1), ULTRASONICO.4, V+RASP.1
M.DERECHO2: 7.4V-01.2, 7.4V-INTE.2, 7.4V-O2.2, TB1.7 (VMOT)
unnamed: TB1.16 (PWMA), U$1.23 (IO25)
unnamed: TB1.10 (PWMB), U$1.26 (IO14)
unnamed: TB1.11 (BIN2), U$1.28 (IO13)
unnamed: TB1.12 (BIN1), U$1.27 (IO12)
unnamed: TB1.15 (AIN2), U$1.24 (IO26)
unnamed: TB1.14 (AIN1), U$1.25 (IO27)
unnamed: M.DERECHO.1, TB1.3 (AO1)
unnamed: M.DERECHO.6, TB1.4 (AO2)
unnamed: M.IZQUIERDO.6, TB1.6 (BO1)
unnamed: M.IZQUIERDO.1, TB1.5 (BO2)
unnamed: M.DERECHO.3, U$1.21 (IO32)
unnamed: M.DERECHO.4, U$1.22 (IO33)
unnamed: M.IZQUIERDO.3, U$1.19 (IO34)
unnamed: M.IZQUIERDO.4, U$1.20 (IO35)
unnamed: SERVO.1, U$1.9 (IO18)
unnamed: IR2.3, J2.11 (GP17)
unnamed: IR1.3, J2.13 (GP27)
unnamed: J2.16 (GP23), ULTRASONICO.2
unnamed: FINALC.1, J2.22 (GP25)
unnamed: 1K.1, 2K.2, J2.18 (GP24)
unnamed: 2K.1, ULTRASONICO.3

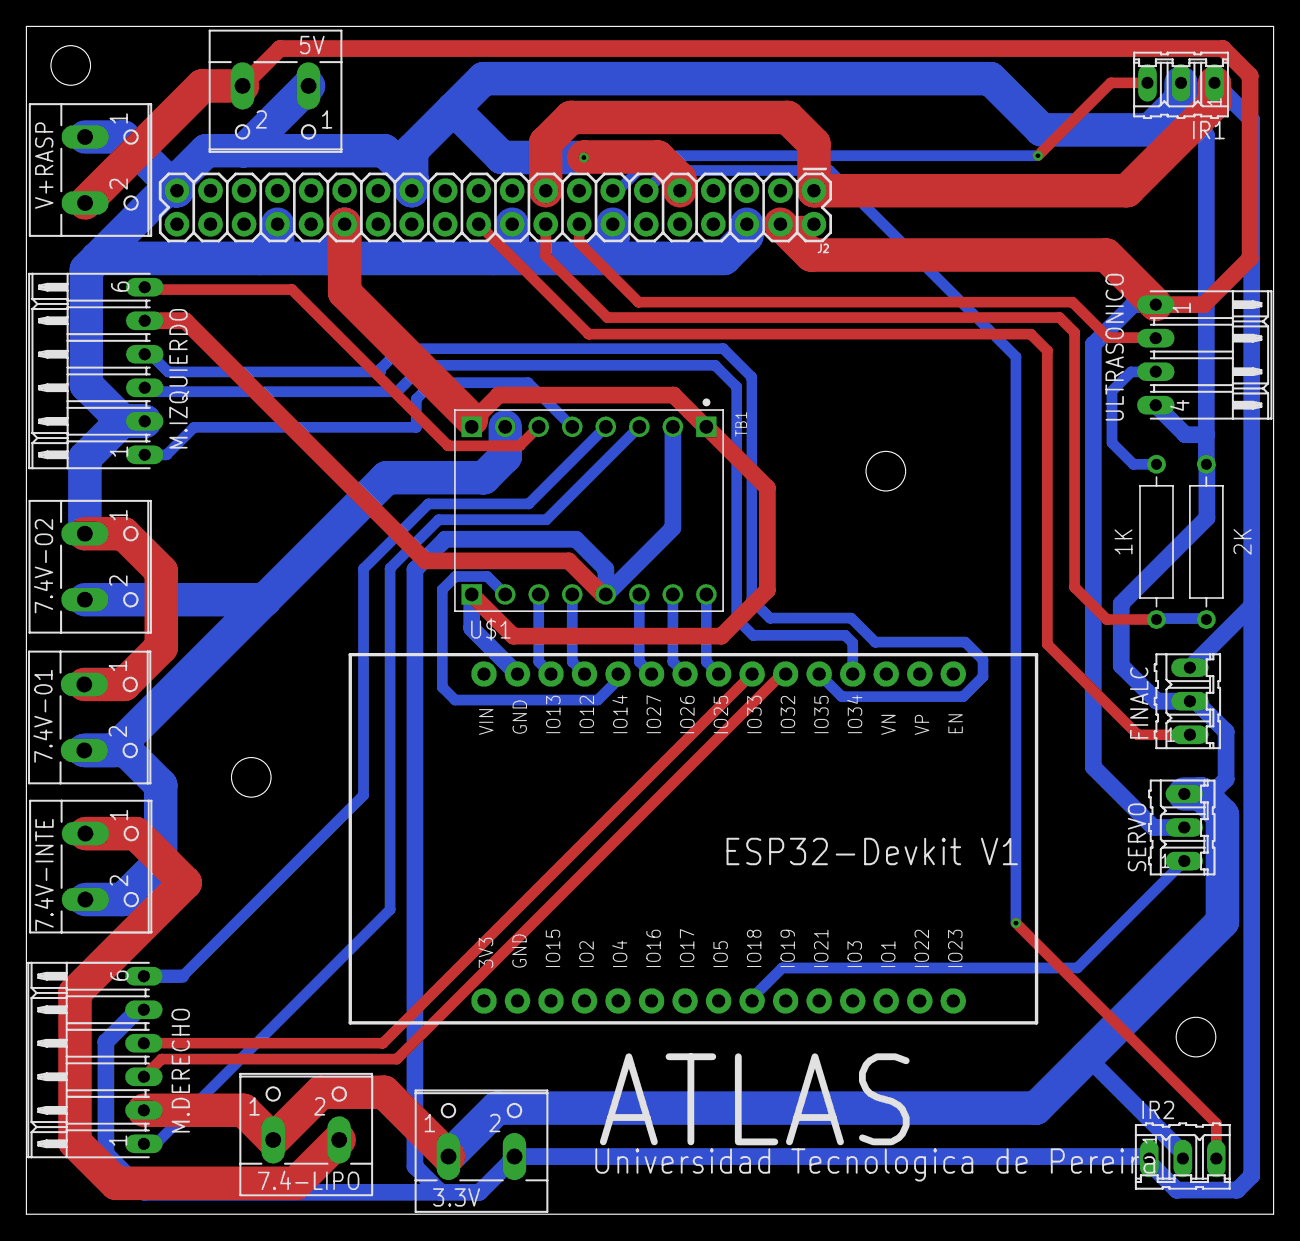
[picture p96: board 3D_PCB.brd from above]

Board: 2 copper layers, 94.5 x 90.0 mm, 19 parts (0 on the bottom side), 26 nets.

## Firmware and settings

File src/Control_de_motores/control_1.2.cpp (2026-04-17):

#include <ESP32Servo.h>
#include <Arduino.h>

Servo servo;
int direccionAnterior = -1;
#define SERVO_PIN 18
#define LED_PIN 2

// ==================== PROTOTIPOS ====================
void aplicarMovimiento(float v, int dir);
void motor1Adelante(int vel);
void motor1Atras(int vel);
void motor2Adelante(int vel);
void motor2Atras(int vel);
void detenerMotores();

// ==================== ECUACIONES ====================
const float A_M1 = 500; //izquierdo rapido
const float B_M1 = 15;

const float A_M2 = 850; //derecho lento
const float B_M2 = 30;

// ==================== CONSTANTES ====================
const float DIAMETRO = 0.067;
const int PPR_M1 = 1340; // izquierdo
const int PPR_M2 = 1221; // derecho
const int INTERVALO_MS = 500;

// 🔥 VELOCIDAD FIJA
float vDeseada = 0.25;

// ==================== PINES ====================
#define AIN1 27
#define AIN2 26
#define PWMA 25

#define BIN1 12
#define BIN2 13
#define PWMB 14

const int ENCODER1_A = 32;
const int ENCODER2_A = 34;

// ==================== VARIABLES ====================
volatile long pulsos1 = 0;
volatile long pulsos2 = 0;

unsigned long tiempoAnterior = 0;

char comando = 0;

// ==================== INTERRUPCIONES ====================
void IRAM_ATTR contarPulso1() { pulsos1++; }
void IRAM_ATTR contarPulso2() { pulsos2++; }

// ==================== SETUP ====================
void setup() {

  // Servo con rango ajustado
  servo.attach(SERVO_PIN, 1000, 2000);
  servo.write(90); // centrado inicial

  Serial.begin(115200);
  pinMode(LED_PIN, OUTPUT);

  // Pines motores
  pinMode(AIN1, OUTPUT);
  pinMode(AIN2, OUTPUT);
  pinMode(BIN1, OUTPUT);
  pinMode(BIN2, OUTPUT);

  // Pines encoders
  pinMode(ENCODER1_A, INPUT_PULLUP);
  pinMode(ENCODER2_A, INPUT_PULLUP);

  attachInterrupt(digitalPinToInterrupt(ENCODER1_A), contarPulso1, RISING);
  attachInterrupt(digitalPinToInterrupt(ENCODER2_A), contarPulso2, RISING);

  // PWM motores
  ledcSetup(2, 5000, 8); //motor izquierdo canal 2
  ledcAttachPin(PWMA, 2);

  ledcSetup(3, 5000, 8);  //motor derecho canal 3
  ledcAttachPin(PWMB, 3);

  tiempoAnterior = millis();
}

// ==================== LOOP ====================
void loop() {

  // 🔹 SOLO DIRECCION
if (Serial.available()) {
  comando = Serial.read();

  if (comando != '\n' && comando != '\r') {
    while (Serial.available()) Serial.read();
  }
}

  // 🔥 convertir comando a dirección
  int dir = 0;

  if (comando == 'a') dir = 1;
  else if (comando == 'i') dir = 3;
  else if (comando == 'd') dir = 2;
  else if (comando == 'x') dir = 0;

  // 🔥 MOVER SERVO SOLO SI CAMBIA
  if (dir != direccionAnterior) {
    moverServo(dir);
    direccionAnterior = dir;
  }

  // 🔥 MOVIMIENTO
  if (dir != 0) {
    aplicarMovimiento(vDeseada, dir);
    digitalWrite(LED_PIN, HIGH);
  } else {
    detenerMotores();
    digitalWrite(LED_PIN, LOW);
  }

  // Medición
  if (millis() - tiempoAnterior >= INTERVALO_MS) {

    noInterrupts();
    long p1 = pulsos1;
    long p2 = pulsos2;
    pulsos1 = 0;
    pulsos2 = 0;
    interrupts();

    float intervalo = INTERVALO_MS / 1000.0;

    float rpm1 = (p1 * (100.0 / intervalo)) / PPR_M1;
    float rpm2 = (p2 * (100.0 / intervalo)) / PPR_M2;

    float vReal1 = (rpm1 * PI * DIAMETRO) / 100.0;
    float vReal2 = (rpm2 * PI * DIAMETRO) / 100.0;

    Serial.print("V1:");
    Serial.print(vReal1, 2);
    Serial.print(" V2:");
    Serial.println(vReal2, 2);

    tiempoAnterior = millis();
  }
}

// ==================== MOVIMIENTO ====================
void aplicarMovimiento(float v, int dir) {

  int pwm1 = constrain((int)(A_M1 * v + B_M1), 0, 255);
  int pwm2 = constrain((int)(A_M2 * v + B_M2), 0, 255);

  // evitar zona muerta
  pwm1 = max(pwm1, 80);
  pwm2 = max(pwm2, 80);

switch (dir) {

  case 1: // ADELANTE
    motor1Adelante(pwm1);
    motor2Adelante(pwm2);
    break;

  case 2: // DERECHA
    motor1Adelante(pwm1);     // izquierda adelante
    detenerMotor2();            // derecha detenida
    break;

  case 3: // IZQUIERDA
    motor2Adelante(pwm2);  // derecha adelante
    detenerMotor1();       // izquierda detenida
    break;

  default:
    detenerMotores();
    break;
}
}

// ==================== MOTORES ====================
void motor1Adelante(int vel) {
  digitalWrite(AIN1, HIGH);
  digitalWrite(AIN2, LOW);
  ledcWrite(2, vel);
}

void motor1Atras(int vel) {
  digitalWrite(AIN1, LOW);
  digitalWrite(AIN2, HIGH);
  ledcWrite(2, vel);
}

void detenerMotor1() {
  digitalWrite(AIN1, LOW);
  digitalWrite(AIN2, LOW);
  ledcWrite(2, 0);
}

void motor2Adelante(int vel) {
  digitalWrite(BIN1, HIGH);
  digitalWrite(BIN2, LOW);
  ledcWrite(3, vel);
}

void motor2Atras(int vel) {
  digitalWrite(BIN1, LOW);
  digitalWrite(BIN2, HIGH);
  ledcWrite(3, vel);
}

void detenerMotor2() {
  digitalWrite(BIN1, LOW);
  digitalWrite(BIN2, LOW);
  ledcWrite(3, 0);
}

void detenerMotores() {
  detenerMotor1();
  detenerMotor2();
}

// ==================== SERVO ====================
void moverServo(int dir) {
  switch (dir) {
    case 1:
      servo.write(90);
      break;
    case 2:
      servo.write(150);
      break;
    case 3:
      servo.write(30);
      break;
    default:
      servo.write(90);
      break;
  }
}

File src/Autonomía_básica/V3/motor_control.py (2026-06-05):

#!/usr/bin/env python3
# motor_control.py - AprilTags + COOLDOWN_TAG no bloqueante + dict líneas

from flask import Flask, Response
from picamera2 import Picamera2
from pupil_apriltags import Detector
import cv2
import numpy as np
import serial
import time
import threading
from gpiozero import DistanceSensor
import multiprocessing as mp
import sys

# ==============================
# Variables globales de estado
# ==============================
qr_logic_activo = False
esperando_qr_logic = False
tiempo_espera_qr_logic = 0
_offset_hasta = 0.0    

ultimo_comando = None
override_activo = False
comando_override = None

estado = "SEGUIR_LINEA"
qr_guardado = None
tiempo_estado = 0

app = Flask(__name__)

# Variables globales de comunicación (se asignan en run_motor_control)
qr_queue = None
action_queue = None
line_status_queue = None
status_queue = None

# ==============================
# Serial
# ==============================
try:
    ser = serial.Serial('/dev/ttyUSB0', 115200, timeout=1)
    serial_lock = threading.Lock()
    time.sleep(2)
    print("[Motor] Puerto serie abierto")
except Exception as e:
    print(f"[Motor] Error al abrir puerto serie: {e}")
    ser = None

# Pulsos acumulados desde último reset (se actualiza desde hilo lector)
pulsos_acumulados = 0

def hilo_lector_serial():
    global pulsos_acumulados
    while True:
        try:
            if ser:
                linea = None
                with serial_lock:
                    if ser.in_waiting > 0:
                        linea = ser.readline().decode('utf-8', errors='ignore').strip()
                if linea and linea.startswith("P1:"):
                    partes = linea.split()
                    p1 = int(partes[0].split(":")[1])
                    p2 = int(partes[1].split(":")[1])
                    pulsos_acumulados = (p1 + p2) // 2
                    # Enviar pulsos directamente aunque esté en override
                    if line_status_queue is not None:
                        try:
                            line_status_queue.put({"pulsos": pulsos_acumulados}, block=False)
                        except:
                            pass
        except:
            pass
        time.sleep(0.02)

threading.Thread(target=hilo_lector_serial, daemon=True).start()

# ==============================
# Controlador PI
# ==============================
Kp = 0.13
Ki = 0.001
integral_error = 0.0
tiempo_pi = time.time()
OFFSET_DERECHA = 300
OFFSET_CENTRO = 0
SERVO_MIN = 40
SERVO_MAX = 140

_ang_suave = 96
SLEW_PI = 6   # grados máx por frame SOLO en seguidor de línea (no afecta S:)
_resume_hasta = 0.0
RESUME_T = 1.2         # s de arranque suave tras un tag/override
RESUME_ANG_MAX = 90     # durante ese tiempo NO gira fuerte a la derecha (roja)

# Debug
_ultimo_log_angulo = 0.0
debug_error = 0
debug_angulo = 90
debug_ambas = False
offset_descarga = 0

# Debounce: frames consecutivos sin línea antes de enviar stop
contador_sin_linea = 0

# ==============================
# Ultrasonido
# ==============================
obstaculo_cercano = False
try:
    sensor = DistanceSensor(echo=24, trigger=23, max_distance=4)
    print("[Motor] Sensor ultrasonido inicializado")
except Exception as e:
    print(f"[Motor] Error ultrasonido: {e}")
    sensor = None

def hilo_ultrasonido():
    global obstaculo_cercano
    while True:
        try:
            if sensor:
                distancias = []
                for _ in range(3):
                    d = sensor.distance * 100
                    if 2 < d < 400:
                        distancias.append(d)
                    time.sleep(0.05)
                if distancias:
                    distancia = sum(distancias) / len(distancias)
                    obstaculo_cercano = distancia <= 20
                else:
                    obstaculo_cercano = False
            else:
                obstaculo_cercano = False
        except Exception as e:
            print(f"[Ultrasonido] Error: {e}")
            obstaculo_cercano = False
        time.sleep(0.3)

threading.Thread(target=hilo_ultrasonido, daemon=True).start()

# ==============================
# Cámara
# ==============================
try:
    picam2 = Picamera2()
    config = picam2.create_video_configuration(main={"size": (1280, 720), "format": "XBGR8888"})
    picam2.configure(config)
    picam2.start()
    picam2.set_controls({
        "AwbEnable": False,
        "ColourGains": (1.4, 1.6),
        "AeEnable": True,
        "ExposureValue": -0.2,
        "Brightness": 0.0,
        "Contrast": 1.2,
        "Saturation": 1.1,
    })
    print("[Motor] Cámara inicializada")
except Exception as e:
    print(f"[Motor] Error cámara: {e}")
    sys.exit(1)

# ==============================
# Detector AprilTag
# ==============================
detector_apriltag = Detector(families="tag36h11")
ultimo_tag_id = None
tiempo_ultimo_tag = 0
cooldown_tag = 0.5

def leer_tag(frame_bgr, bbox_marco=None, margen=20):
    """Detecta AprilTags. Si se pasa bbox_marco, solo acepta el tag cuyo
    centro caiga dentro de ese marco (con un margen de tolerancia en px)."""
    global ultimo_tag_id, tiempo_ultimo_tag

    gray = cv2.cvtColor(frame_bgr, cv2.COLOR_BGR2GRAY)
    resultados = detector_apriltag.detect(gray)
    if not resultados:
        return False, None, None

    candidatos = resultados

    # 🔒 Anclar la lectura al marco validado
    if bbox_marco is not None:
        mx, my, mw, mh = bbox_marco
        x1, y1 = mx - margen, my - margen
        x2, y2 = mx + mw + margen, my + mh + margen
        candidatos = []
        for t in resultados:
            cx, cy = t.center  # centro del tag en píxeles (full frame)
            if x1 <= cx <= x2 and y1 <= cy <= y2:
                candidatos.append(t)

    candidatos = [t for t in candidatos
                  if cv2.contourArea(t.corners.astype(np.float32)) >= 800]  # ajusta según tu cámara

    if not candidatos:
        return False, None, None

    # Entre los que están dentro del marco, el más grande (= el más cercano)
    tag = max(candidatos, key=lambda t: cv2.contourArea(t.corners.astype(np.float32)))
    tag_id = tag.tag_id
    ahora = time.time()

    if tag_id != ultimo_tag_id or (ahora - tiempo_ultimo_tag) > cooldown_tag:
        ultimo_tag_id = tag_id
        tiempo_ultimo_tag = ahora
        return True, tag_id, tag.corners

    return False, None, None
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

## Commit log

2026-02-20 creacion de archivos readme
2026-02-21 codigo de prueba
2026-03-11 control de motores y encoder
2026-03-12 DISEÑOS
    [ACOPLE_RUEDA_BARRA_DER (1).stl, ACOPLE_RUEDA_BARRA_DER.stl, ACOPLE_RUEDA_BARRA_IZQ (1).stl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]
2026-03-12 Cambios en las carpetas para organizar mejor
    [ACOPLE_RUEDA_BARRA_DER (1).stl, ACOPLE_RUEDA_BARRA_DER.stl, ACOPLE_RUEDA_BARRA_IZQ (1).stl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]
2026-03-12 cambio de nombres raiz
    [ACOPLE_RUEDA_BARRA_DER (1).stl, ACOPLE_RUEDA_BARRA_DER.stl, ACOPLE_RUEDA_BARRA_IZQ (1).stl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]
2026-03-12 cambios en el nombre de la carpeta documentacion
2026-03-12 cambios de archivos stl a readme
    [ACOPLE_RUEDA_BARRA_DER (1).stl, ACOPLE_RUEDA_BARRA_DER.stl, ACOPLE_RUEDA_BARRA_IZQ (1).stl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]
2026-03-13 documentacion de mecanica
2026-03-13 imagenes insertadas
2026-03-13 documentacion de los codigos
2026-03-13 actualizacion en la documentación
2026-03-13 cambios en el apartado principal
2026-03-20 eliminacion de codigos que no se usan
2026-03-20 comunicacion raspberry con esp32
2026-03-20 eliminacion de un codigo
2026-04-14 nueva version del codigo de obstaculo camara
2026-04-15 nueva version de codigo v2
2026-04-17 nuevas carpetas y orden nuevo en la carpeta src acerca de los codigos de la raspberry
2026-04-17 cambios en el codigo 1.2
2026-04-17 cambios en el README
2026-04-18 cambios en el codigo obstaculos 2.1
2026-04-20 cambios en el umbral
2026-04-20 cambios en el codigo 2.1
2026-04-24 nuevos cambios en codigos de ultrasonidos
2026-04-28 cambios en el codigo 2.2
2026-04-28 aumento de roi
2026-04-28 nuevos codifgos para lectura de qr
2026-04-28 codigo de qr
2026-05-09 WIP: guardar cambios locales antes de reparar .git
2026-05-11 codigo nuevo para probar lectura de qr nuevos
2026-05-12 cambios en control motor
2026-05-19 Cambios en la carpeta src programacion
2026-05-19 cambios en el src
2026-05-19 nuevos cambios en la carpeta de pruebas
2026-05-19 cambio en la carpeta pruebas
2026-05-19 nuevos readme en cada carpeta de codigo
2026-05-19 readme control de motores
2026-05-19 nuevos readme en la carpeta mechanical
2026-05-20 cambios en v2 de programacion
2026-05-20 cambios en motor
2026-05-22 ir para funcionar
2026-05-22 hasta la inter del tag 9
2026-05-22 hasta la inter del tag 9 y regresa al incio, primera estacion de descarga lista
2026-05-22 afinacion de lectura de tag
2026-05-22 afinacion de primera interseccion
2026-05-26 eliminacion de V3
2026-05-27 inter 2 mejorar la eliminacion de la dos lineas
2026-05-28 codigo con inter buena, lipo 8 v ajustar seg
2026-05-28 nuevo codigo de la esp32 y de V3 para hacer interseccion con endoders
2026-05-28 intersecciones con encoders
2026-05-28 cambios en el tag 10 para continuar el proceso
2026-05-29 deteccion qr mejorada circuito completo
2026-05-29 codigo listo con encoders en intersecciones
2026-05-29 codigo listo con encoders en las inter
2026-05-29 CI2 con cinco seg de 90 grados
2026-06-05 cambios en la carpeta src
    [MATRIZ_CONTROL_DE_DOCUMENTOS.xlsx]

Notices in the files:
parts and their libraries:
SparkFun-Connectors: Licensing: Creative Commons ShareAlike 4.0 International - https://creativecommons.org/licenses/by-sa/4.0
